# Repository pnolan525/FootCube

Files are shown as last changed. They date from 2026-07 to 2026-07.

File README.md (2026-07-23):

# FootCube
<p align="center">
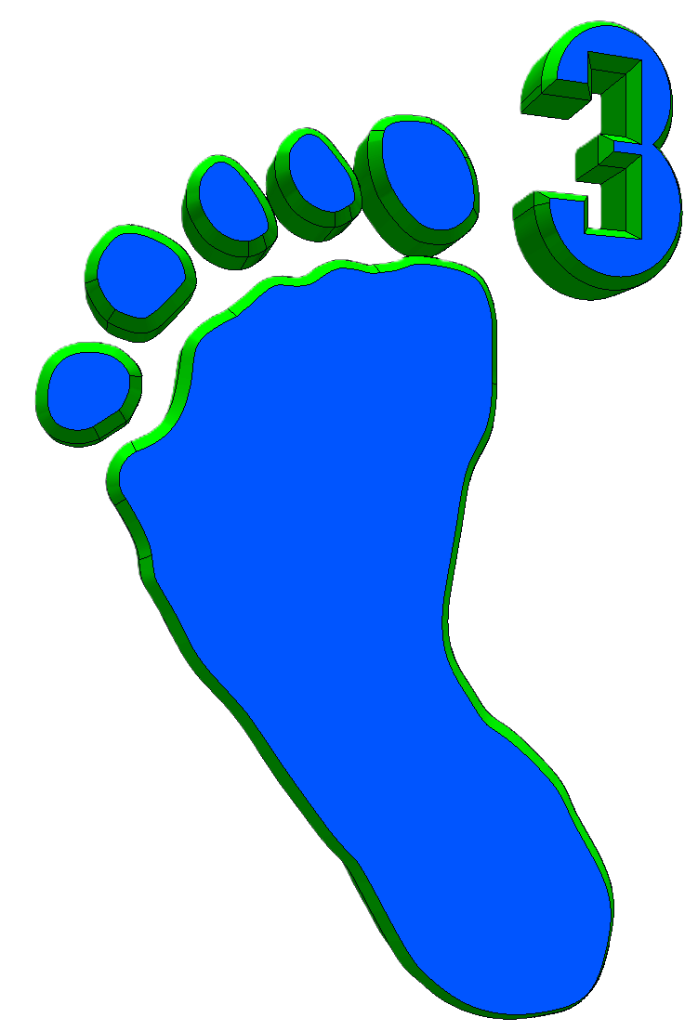
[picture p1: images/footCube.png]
FootCube
  
</p>
Modification for the Voron Trident 300Cube printed parts to fit 1"x1" extrusion.

To maintain the belt path the A and B drive pulleys use four M5x30 SCHS in place of the M5x30 BHCS. 
There is a long shaft motor version of the A_Drive_Frame_Lower part that does not require supports. If the long shaft stepper motor is not used the motor must be set into the A_Drive_Frame_Lower part to maintain belt path.
I tried to keep everything as close to the original as possible. Below are a list of the BOM Changes.
# FRAME
| New Length | Machining | Qty | Equivalent LDO Part | Equivalent Misumi Part | Description | Machining Key |
|---:|---|----:|---|---|---|---|
| 22.25 | LCP, RCP, AV16.5 | 4 | LDO-VTDF300C-2020T-550-LCP-RCP-AV (B) | Misumi HFSB5-2020-550-LCP-RCP-AV430 | Vertical extrusions with blind joint access holes pre-drilled | AV (Distance from the Left End Plane) = Vertical Wrench Hole Machining |
| 16.625 | TPW | 9 | LDO-VTDF300C-2020T-420-TPW (A) | Misumi HFSB5-2020-420-TPW | Horizontal extrusions for outer frame and Gantry | LCP = 1 Row Wrench Hole Crisscross from Left End Face |
| 16.625 | TPW, AH8.3125 | 1 | LDO-VTDF300C-2020T-420-AH-TPW (C) | Misumi HFSB5-2020-420-AH210-TPW | Lower rear horizontal extrusion | TPW = Both End Tapped |
| 15 | LTP | 1 | LDO-VTDF300C-2020T-380-LTP (E) | Misumi HFSB5-2020-380-LTP | Vertical rear center extrusion | LTP = Left End Tapped |
| 16.625 | AH8.3125 | 1 | LDO-VTDF300C-2020T-420-AH (F) | Misumi HFSB5-2020-420-AH210 | Front bed extrusion | AH (Distance from the Left End Plane) = Horizontal Wrench Hole Machining |
| 11 | LTP | 1 | LDO-VTDF300C-2020T-282-LTP (G)\* | Misumi HFSB5-2020-282-LTP | Rear bed extrusion | RCP = 1 Row Wrench Hole Crisscross from Right End Face |
| 11.5 | - | 1 | LDO-VTDF300C-2020T-290 (D)\* | Misumi HFSB5-2020-290 | Rear Cross Bar for Gantry: X Spec Dimension − 10 mm | |
| 15 | - | 1 | LDO-VTDF300C-2020T-380 (H) | Misumi HFSB5-2020-380 | X Axis Extrusion: X Spec Dimension + 80 mm | |

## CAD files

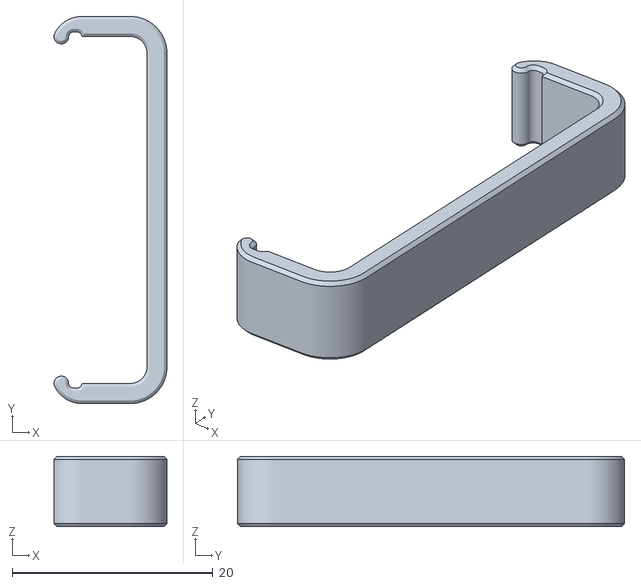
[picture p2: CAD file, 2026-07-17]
STL/ElectronicsBay/DIN_Center_Support_x2.stl
11.3 x 38.6 x 7.00

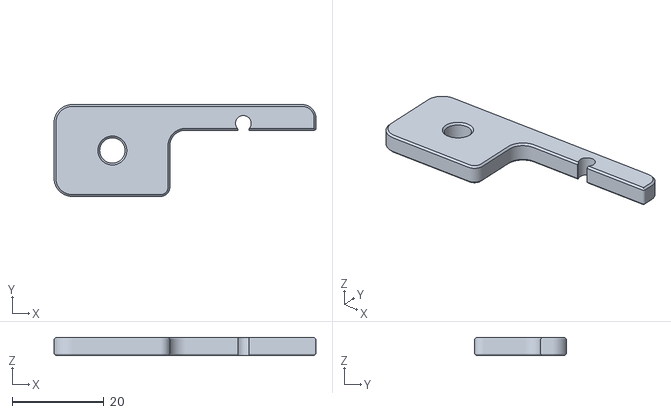
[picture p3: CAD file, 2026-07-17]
STL/Exhaust_Filter/Exhaust_Filter_Mount_x2.stl
57.0 x 20.0 x 4.00

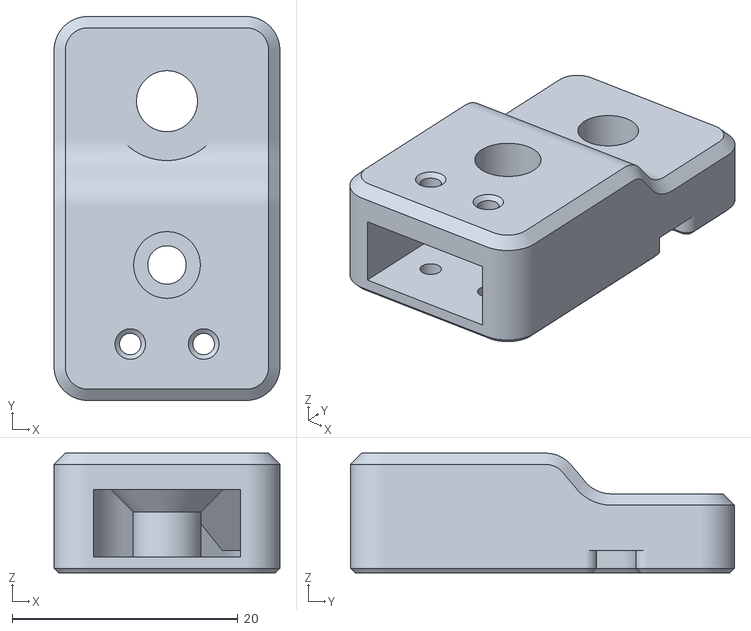
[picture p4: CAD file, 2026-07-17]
STL/Gantry/AB_Drive_Units/Y_Endstop_Housing.stl
20.0 x 34.0 x 10.6

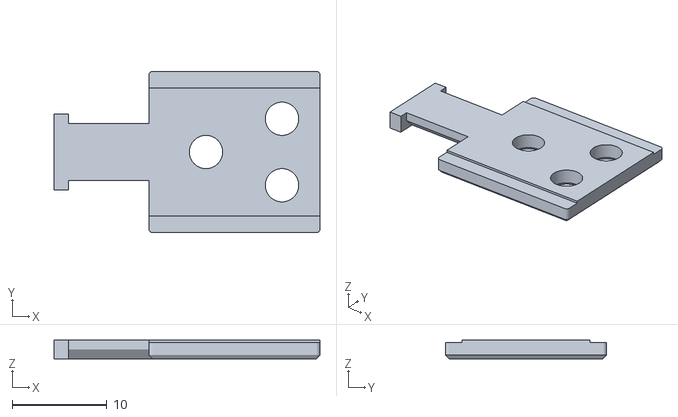
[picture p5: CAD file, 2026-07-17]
STL/Gantry/Chain_Wire_Anchor_3hole_x2.stl
28.0 x 17.0 x 2.00

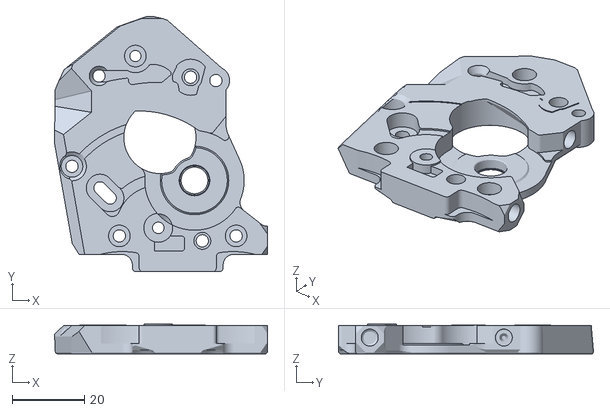
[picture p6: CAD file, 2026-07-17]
STL/Gantry/X_Axis/X_Carriage/Direct_Feed/Extruder_Motor_Plate.stl
59.1 x 70.8 x 8.20

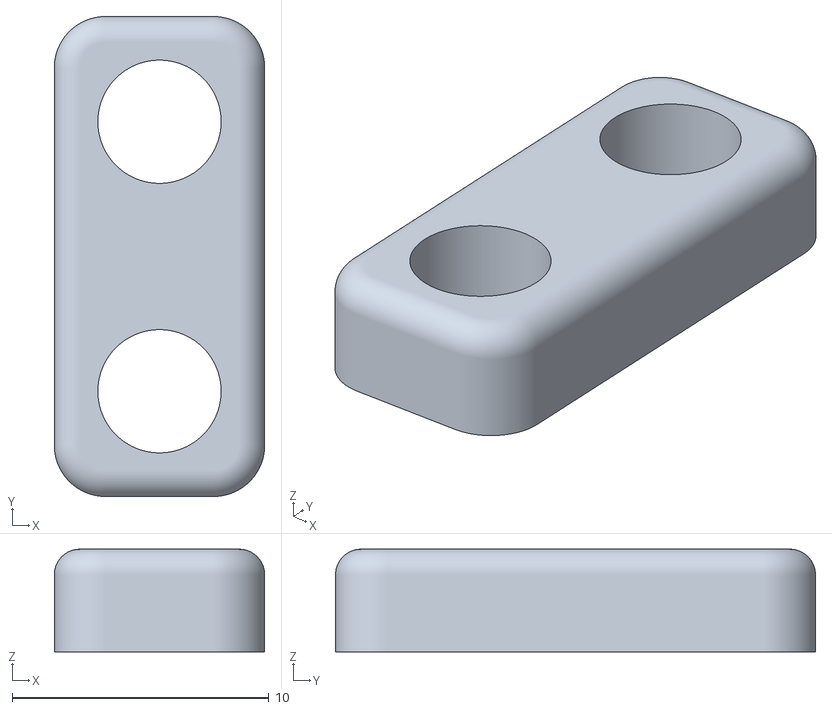
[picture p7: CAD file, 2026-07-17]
STL/Gantry/X_Axis/X_Carriage/probe_retainer_bracket.stl
8.20 x 18.7 x 4.00

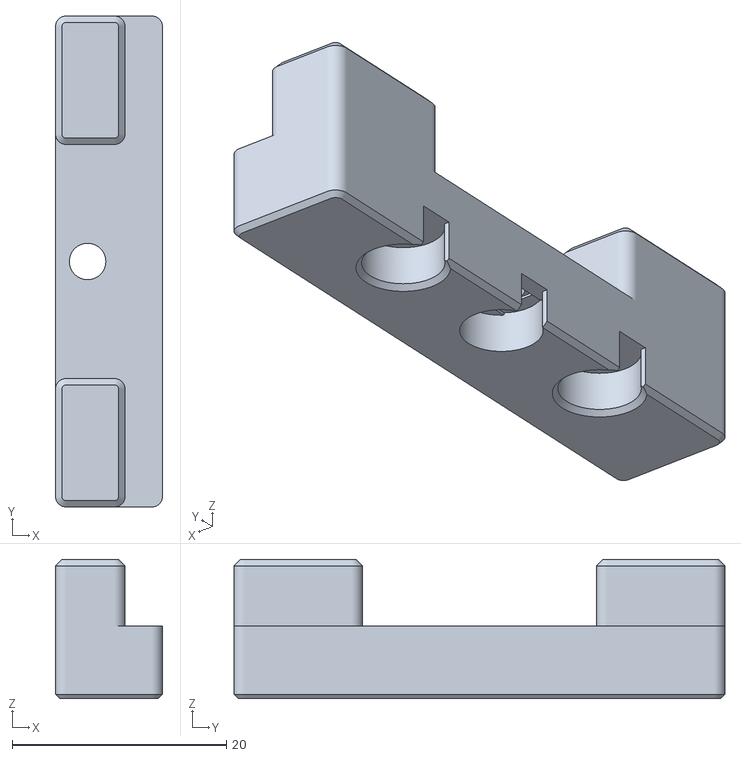
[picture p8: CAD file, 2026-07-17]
STL/Panels/Front_Doors/Latch_x2.stl
10.0 x 45.9 x 13.0

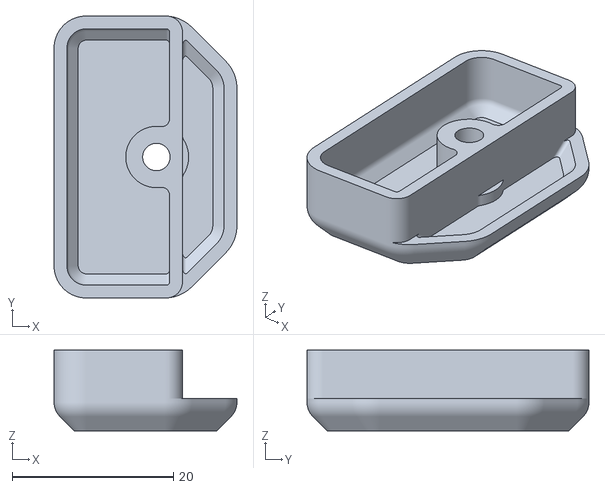
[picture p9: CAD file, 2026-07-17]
STL/Panels/Midspan_Panel_Clip_6mm_x8.stl
22.7 x 35.0 x 10.00

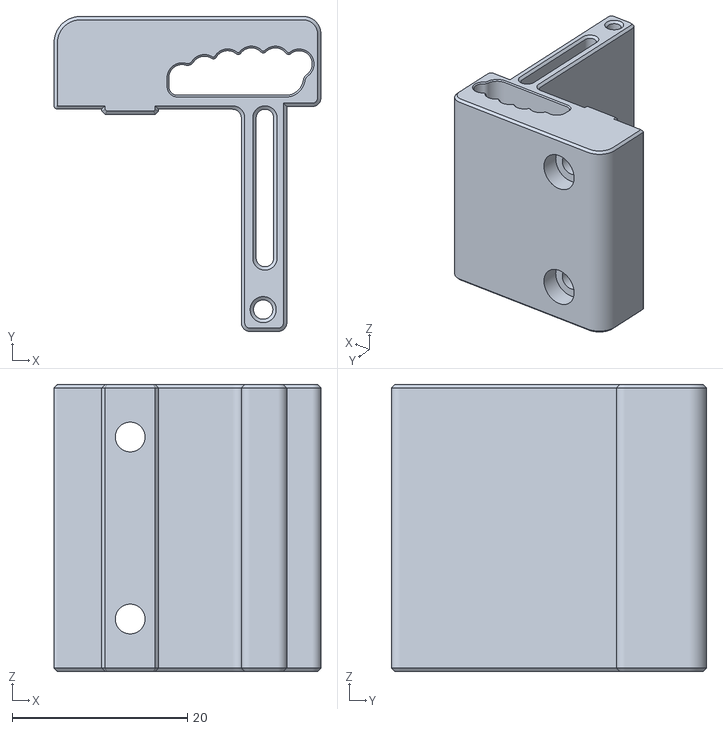
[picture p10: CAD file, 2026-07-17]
STL/Skirt/mini12864_Case_Hinge.stl
30.5 x 36.0 x 32.8

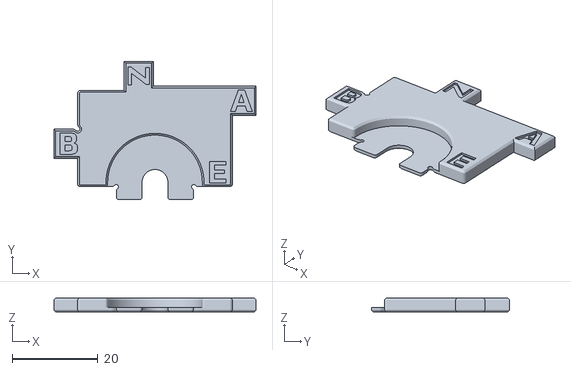
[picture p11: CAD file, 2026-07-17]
STL/Tools/pulley_jig.stl
47.0 x 32.2 x 3.20

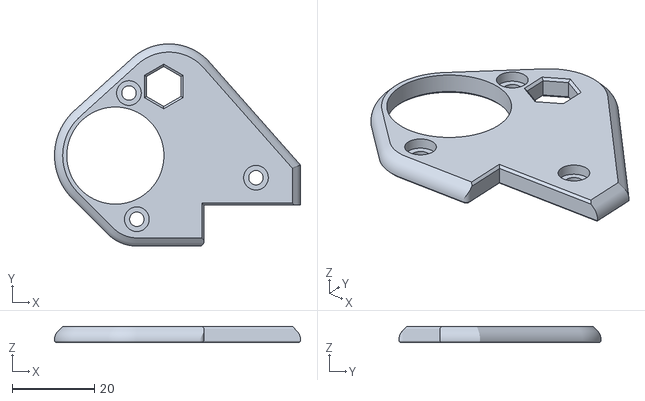
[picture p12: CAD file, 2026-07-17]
STL/Z_Assembly/[a]_Z_Carriage_Left.stl
59.8 x 49.1 x 4.00

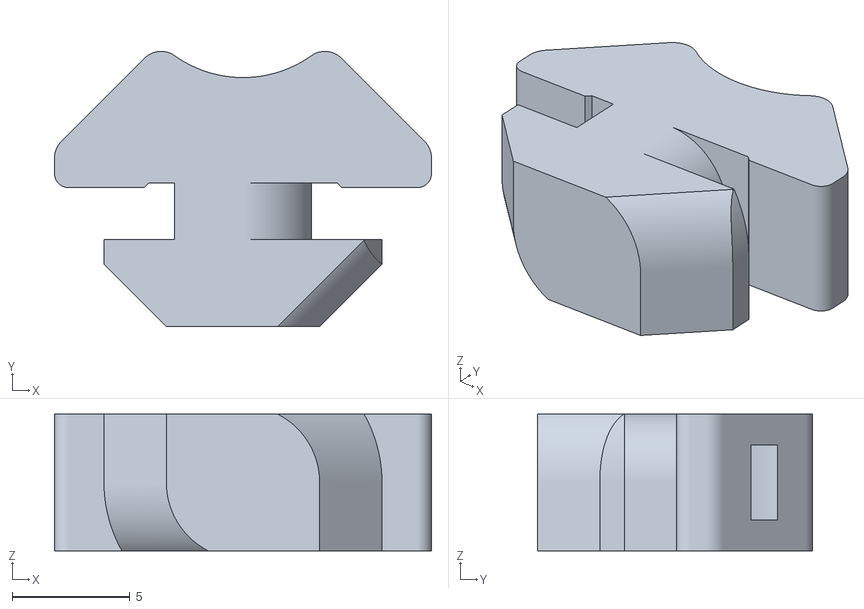
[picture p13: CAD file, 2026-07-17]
STL/ElectronicsBay/Cable_Frame_Anchor_x6.stl
16.0 x 11.7 x 5.80

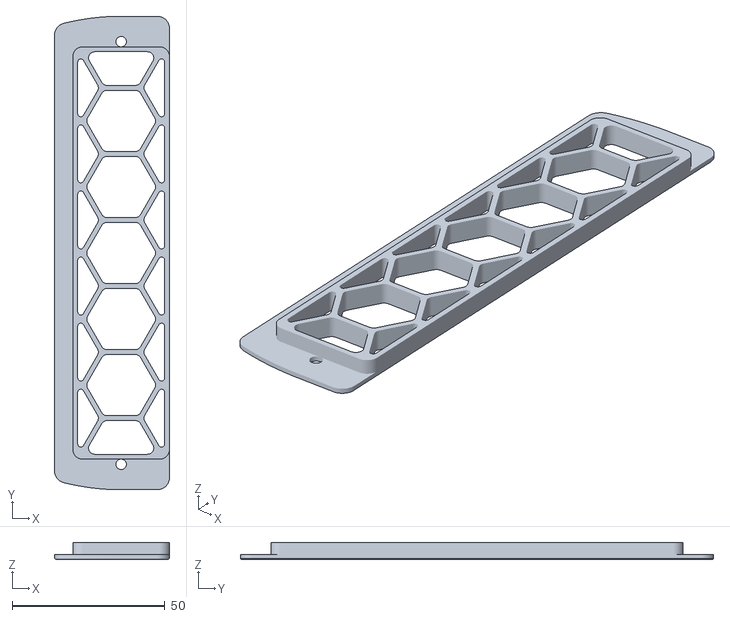
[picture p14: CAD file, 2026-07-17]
STL/Exhaust_Filter/Exhaust_Filter_Grill.stl
37.6 x 154.8 x 5.60

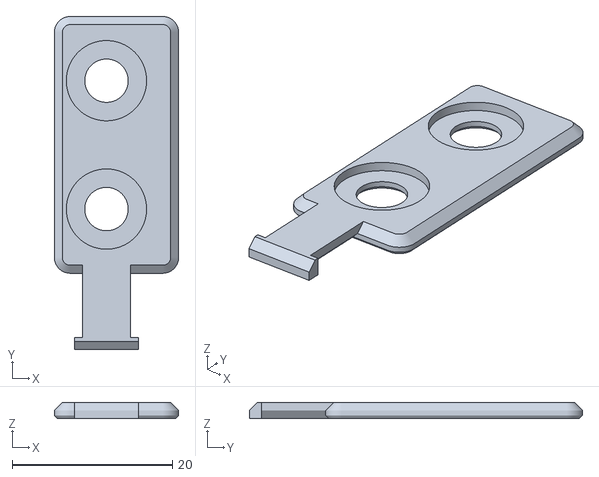
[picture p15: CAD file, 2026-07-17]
STL/Gantry/Chain_Wire_Anchor_A_3hole.stl
15.5 x 41.5 x 2.00

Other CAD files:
STL/Gantry/X_Axis/X_Carriage/Direct_Feed/Chain_Anchor_3_Hole.stl
STL/Panels/Midspan_Panel_Clip_4mm_x7.stl
STL/Skirt/Fan_Grill_Retainer_x2.stl
STL/Tools/MGN12_rail_guide_x2.stl
STL/ElectronicsBay/Deck_Support_x6.stl
STL/ElectronicsBay/LRS_PSU_Bracket_x2.stl
STL/ElectronicsBay/PCB_DIN_Clip_x3.stl
STL/ElectronicsBay/RS25_PSU_Bracket.stl
STL/ElectronicsBay/WAGO_221-415_corner_mount.stl
STL/Exhaust_Filter/60mm_Exhaust_Fan_Grill.stl
STL/Panels/bottom_panel_clip_x4.stl
STL/Skirt/BTT_Knob_Light_Shield.stl
STL/Skirt/Fan_Grill_A_x2.stl
STL/Skirt/Fan_Grill_B_x2.stl
STL/Skirt/Keystone_Blank_Insert_x2.stl
STL/Skirt/Skirt_Logo_Insert_x2.stl
STL/Tools/4-125in_Y_Alignment_Spacer.stl
STL/Tools/5-625in_extrusion_drill_guide.stl
STL/Tools/MGN9_rail_guide_x2.stl
STL/Tools/half_inch_extrusion_drill_guide.stl
STL/Z_Assembly/Nozzle_Probe.stl
STL/Z_Assembly/Wago_221-412_Mount.stl
STL/Z_Assembly/Z_Bed_Rear.stl
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

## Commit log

2026-05-13 Create CAD
    Folder to hold CAD files
2026-05-13 Add files via upload
    Assembly .stp
2026-05-23 Add STL
2026-07-17 STLs and updated step
    STLs and updated step
    [4-125in_Y_Alignment_Spacer.stl, 5-625in_extrusion_drill_guide.stl, 60mm_Exhaust_Fan_Grill.stl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]
2026-07-23 Add frame specifications and equivalent parts to README
    Updated the README to include a new frame section with detailed machining specifications and equivalent parts.
